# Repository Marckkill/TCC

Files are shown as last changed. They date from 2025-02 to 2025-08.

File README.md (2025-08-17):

# TCC - Sistema de Controle de Motor Trifásico com ESP32

Este repositório contém o projeto de TCC (Trabalho de Conclusão de Curso) que implementa um sistema de controle de motor trifásico utilizando ESP32 com modulação SPWM (Sinusoidal Pulse Width Modulation).

## 📋 Sobre o Projeto

O sistema desenvolvido é um inversor trifásico baseado no microcontrolador ESP32-S3, capaz de gerar sinais SPWM para acionamento de motores AC trifásicos. O projeto inclui monitoramento em tempo real de corrente e tensão, além de sistemas de proteção e segurança.

### Características Principais

- **Controle SPWM**: Modulação senoidal PWM trifásica com frequência configurável
- **Monitoramento em Tempo Real**: Leitura contínua de tensão e corrente RMS
- **Sistema de Proteção**: Detecção de sobrecorrente, sobretensão e falhas do sistema
- **Interface Serial**: Controle e monitoramento via comandos seriais
- **Hardware Personalizado**: PCB desenvolvida especificamente para o projeto

## 📁 Estrutura do Projeto

```
TCC/
├── 📄 Esquemáticos KiCad
│   ├── TCC.kicad_sch           # Esquemático principal
│   ├── filtro.kicad_sch        # Circuito de filtros
│   ├── fonte.kicad_sch         # Sistema de alimentação
│   ├── mcu.kicad_sch           # Microcontrolador ESP32
│   ├── sdf.kicad_sch           # Sistema de detecção de falhas
│   └── smp.kicad_sch           # Sistema de medição de potência
│
├── 🔧 Hardware
│   ├── TCC.kicad_pcb           # Layout da PCB
│   ├── TCC.kicad_pro           # Projeto KiCad
│   └── Componentes_Custom/     # Componentes personalizados
│       ├── ESP32/              # Footprint ESP32-S3
│       ├── FSBB30CH60/         # Módulo de potência
│       └── PJ320A/             # Conector de áudio
│
├── 💻 Firmware
│   └── Firmware.ino            # Código principal do ESP32
│
├── 📚 Documentação
│   ├── TCC.pdf                 # Documentação completa
│   ├── TCC-Fonte.pdf           # Esquemático da fonte
│   ├── TCC-MCU.pdf             # Esquemático do MCU
│   └── TCC-SMP.pdf             # Sistema de medição
│
└── 🔄 Backups
    └── TCC-backups/            # Backups automáticos do projeto
```

## 🔧 Hardware

### Componentes Principais

| Componente | Modelo/Tipo | Função |
| --- | --- | --- |
| **Microcontrolador** | ESP32-S3 | Controle principal do sistema  |
| **Módulo de Potência** | FSBB30CH60C | Inversor trifásico de potência |
| **Sensores de Corrente** | SCT013 (6x) | Monitoramento de corrente AC |
| **Sensores de Tensão** | ZMPT (3x) | Monitoramento de tensão AC |
| **Conector** | PJ320A | Interface de entrada de áudio  |

### Especificações Técnicas

- **Tensão de Entrada**: Barramento DC variável
- **Frequência de Saída**: 50 Hz (configurável)
- **Frequência PWM**: 10 kHz
- **Corrente Máxima**: 5A por fase (com proteção)
- **Tempo Morto**: 2μs entre chaves complementares
- **Taxa de Amostragem ADC**: 20 kHz

### Pinagem do ESP32-S3

#### Sinais PWM

```
Fase U: GPIO 18 (Alto), GPIO 35 (Baixo)
Fase V: GPIO 13 (Alto), GPIO 21 (Baixo)
Fase W: GPIO 14 (Alto), GPIO 17 (Baixo)
```

#### Sensores de Corrente (ADC1)

```
U_IN:  GPIO 1  (ADC1_CH0)    U_OUT: GPIO 2  (ADC1_CH1)
V_IN:  GPIO 3  (ADC1_CH2)    V_OUT: GPIO 4  (ADC1_CH3)
W_IN:  GPIO 5  (ADC1_CH4)    W_OUT: GPIO 6  (ADC1_CH5)
```

#### Sensores de Tensão (ADC1)

```
Tensão U: GPIO 7  (ADC1_CH6)
Tensão V: GPIO 8  (ADC1_CH7)
Tensão W: GPIO 9  (ADC1_CH8)
Vbus:     GPIO 10 (ADC1_CH9)
```

#### Segurança

```
VFO (Status): GPIO 36 (INPUT_PULLUP)
```

## 💻 Firmware

### Funcionalidades Implementadas

#### 🌊 Geração SPWM

- Modulação senoidal PWM trifásica
- Defasagem de 120° entre fases
- Índice de modulação configurável (0.1 - 1.0)
- Atualização a 1 kHz para suavidade do sinal

#### 📊 Monitoramento em Tempo Real

- **ADC Contínuo com DMA**: 20 kHz de amostragem
- **Cálculo RMS**: Janela deslizante de 400 amostras (20ms)
- **Buffer Circular**: Armazenamento eficiente de dados
- **Multitarefa**: Processamento paralelo com FreeRTOS

#### 🛡️ Sistema de Proteção

- **Sobrecorrente**: Trip em >5A por fase
- **Sobretensão**: Monitoramento do barramento DC
- **Status VFO**: Verificação do módulo de potência
- **Parada de Emergência**: Desabilitação imediata em falhas

#### 📡 Interface Serial

Comandos disponíveis:

```
start              - Iniciar o inversor
stop               - Parar o inversor
status             - Mostrar status do sistema
sensors            - Mostrar leituras dos sensores
reset              - Limpar falhas do sistema
set_mod <valor>    - Definir índice de modulação (0.1-1.0)
help               - Mostrar ajuda
```

### Principais Funções do Código

| Função | Descrição |
| --- | --- |
| `setup_mcpwm()` | Configuração do módulo MCPWM para SPWM |
| `setup_adc_continuous()` | Inicialização do ADC contínuo com DMA  |
| `update_spwm()` | Atualização dos duty cycles senoidais  |
| `calculate_rms_from_buffer()` | Cálculo RMS das amostras |
| `check_safety_conditions()` | Verificação das condições de segurança |
| `emergency_stop()` | Parada de emergência do sistema |

## 🚀 Como Usar

### Pré-requisitos

#### Software

- [Arduino IDE](https://www.arduino.cc/en/software) 2.0+
- [KiCad](https://www.kicad.org/) 7.0+ (para visualizar esquemáticos)
- Bibliotecas ESP32 (esp32 by Espressif Systems)

#### Hardware

- ESP32-S3 Development Board
- Módulo FSBB30CH60C
- Sensores SCT013 e ZMPT
- Fonte de alimentação adequada

### Instalação e Configuração

1. **Clone o repositório**:

   ```bash
   git clone https://github.com/usuario/TCC.git
   cd TCC
   ```

2. **Configure o Arduino IDE**:

   - Instale o pacote ESP32
   - Selecione "ESP32S3 Dev Module"
   - Configure a porta serial correta

3. **Compile e envie o firmware**:
   - Abra `Firmware/Firmware.ino`
   - Compile (Ctrl+R)
   - Envie para o ESP32 (Ctrl+U)

### Operação do Sistema

1. **Inicialização**:

   ```
   Sistema inicializado - Pronto para operação
   Comandos: start, stop, status, sensors, reset, set_mod <0.1-1.0>
   AVISO: Verifique todos os sistemas de segurança antes de iniciar!
   ```

2. **Verificar sensores**:

   ```
   sensors
   ```

3. **Iniciar o inversor**:

   ```
   start
   ```

4. **Monitorar operação**:
   ```
   status
   ```

### Exemplo de Uso

```bash
# Monitor serial a 115200 baud
sensors          # Verificar leituras
set_mod 0.5      # Configurar índice de modulação para 50%
start            # Iniciar operação
status           # Verificar status
stop             # Parar operação
```

## 📊 Monitoramento

### Dados Disponíveis

O sistema monitora continuamente:

- **Correntes RMS**: 6 canais (entrada e saída por fase)
- **Tensões RMS**: 3 fases + barramento DC
- **Status de Segurança**: VFO, sobrecorrente, sobretensão
- **Parâmetros SPWM**: Ângulo atual, índice de modulação

### Exemplo de Saída do Monitor

```
=== LEITURAS DOS SENSORES ===
Correntes (A):
  U_IN: 2.34  U_OUT: 2.31
  V_IN: 2.35  V_OUT: 2.33
  W_IN: 2.36  W_OUT: 2.34
Tensões (V):
  U: 230.1  V: 229.8  W: 230.3
Tensão Vbus: 325.4 V
Status VFO: OK
Índice de Modulação: 0.800
=============================
```

## 🛡️ Segurança

### Sistemas de Proteção Implementados

1. **Sobrecorrente**: Monitoramento contínuo com trip em 5A
2. **Sobretensão**: Proteção do barramento DC
3. **VFO**: Monitoramento do status do módulo de potência
4. **Tempo Morto**: Prevenção de curto-circuito entre chaves

### ⚠️ Avisos de Segurança

- **ALTA TENSÃO**: Este projeto trabalha com tensões perigosas
- **Sempre desligue a alimentação** antes de fazer conexões
- **Verifique todas as conexões** antes de energizar
- **Use EPIs adequados** durante testes
- **Tenha um sistema de parada de emergência** sempre acessível

## 🔄 Desenvolvimento

### Estrutura do Código

```cpp
// Configurações principais
#define PWM_FREQUENCY 10000        // 10 kHz
#define MODULATION_FREQUENCY 50    // 50 Hz
#define ADC_SAMPLE_FREQ_HZ 20000   // 20 kHz
#define MAX_CURRENT_AMPS 5.0       // 5A máximo

// Loop principal
void loop() {
    update_spwm();              // Atualiza SPWM (1 kHz)
    update_sensors();           // Lê sensores (100 Hz)
    check_safety_conditions();  // Verifica segurança
    process_serial_commands();  // Processa comandos
}
```

### Tecnologias Utilizadas

- **ESP-IDF**: Framework nativo do ESP32
- **FreeRTOS**: Sistema operacional em tempo real
- **MCPWM**: Módulo PWM dedicado do ESP32
- **ADC Contínuo**: Amostragem de alta velocidade com DMA
- **KiCad**: Design de circuitos e PCB

## 📈 Melhorias Futuras

- [ ] Controle de velocidade com feedback
- [ ] Interface web para controle remoto
- [ ] Controle de torque
- [ ] Algoritmos de controle avançados (FOC)
- [ ] Análise de espectro harmônico
- [ ] Comunicação CAN/Modbus
- [ ] Sistema de logs em cartão SD

## 📄 Documentação

### Arquivos de Documentação

- **[TCC.pdf](TCC.pdf)**: Documentação completa do projeto
- **[TCC-Fonte.pdf](TCC-Fonte.pdf)**: Detalhes do sistema de alimentação
- **[TCC-MCU.pdf](TCC-MCU.pdf)**: Circuito do microcontrolador
- **[TCC-SMP.pdf](TCC-SMP.pdf)**: Sistema de medição de potência

### Referências Técnicas

- [ESP32-S3 Technical Reference Manual](https://www.espressif.com/sites/default/files/documentation/esp32-s3_technical_reference_manual_en.pdf)
- [FSBB30CH60C Datasheet](https://www.onsemi.com/pdf/datasheet/fsbb30ch60c-d.pdf)
- Normas de segurança para inversores de frequência

## 👨‍💻 Autor

**José Fonseca**

- Projeto de TCC - Engenharia Eletrônica

## 📝 Licença

Este projeto foi desenvolvido como Trabalho de Conclusão de Curso (TCC) e está disponível para fins educacionais e de pesquisa.

---

## 🆘 Suporte

Para dúvidas ou problemas:

1. Verifique a documentação técnica incluída
2. Consulte os comentários no código fonte
3. Revise as configurações de hardware
4. Verifique as conexões elétricas

**⚠️ LEMBRE-SE: Segurança sempre em primeiro lugar ao trabalhar com sistemas de potência!**

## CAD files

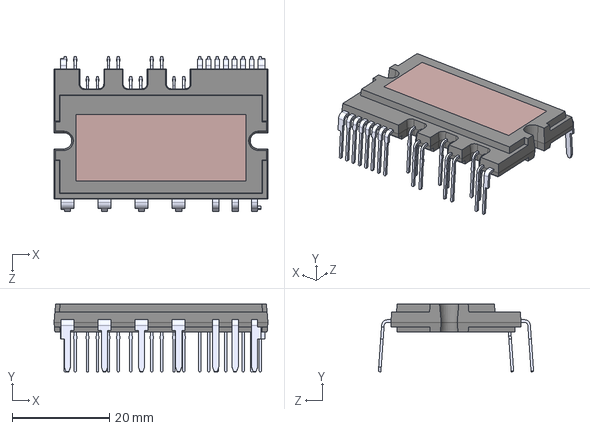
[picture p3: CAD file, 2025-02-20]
Componentes_Custom/FSBB30CH60/FSBB30CH60C.STEP
44.0 x 13.9 x 31.9 mm

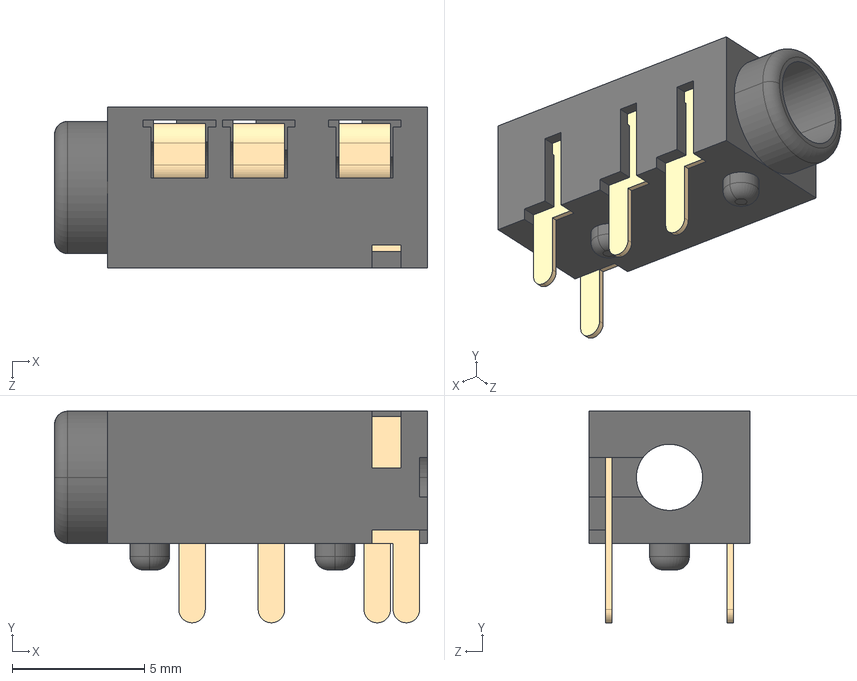
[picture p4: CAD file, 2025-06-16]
Componentes_Custom/PJ320A/PJ320A.STEP
14.1 x 8.00 x 6.10 mm
PJ320A蝶褲
PJ320A-Pin-A x 3
PJ320A-Pin-B

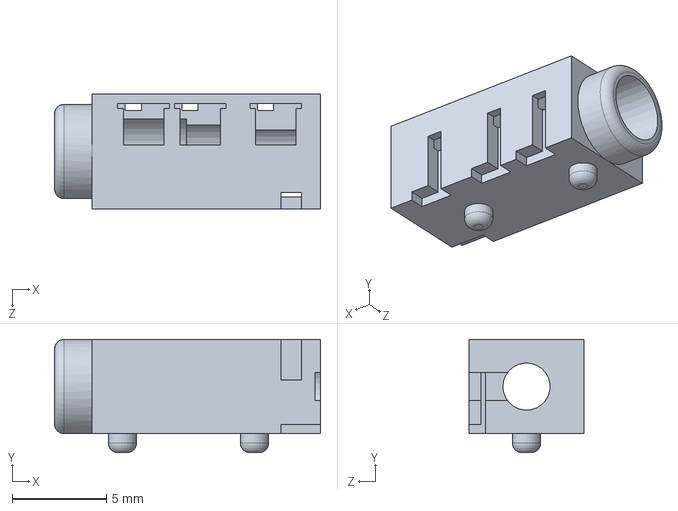
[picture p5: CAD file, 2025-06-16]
Componentes_Custom/PJ320A/PJ320A胶壳.SLDPRT
14.1 x 6.00 x 6.10 mm

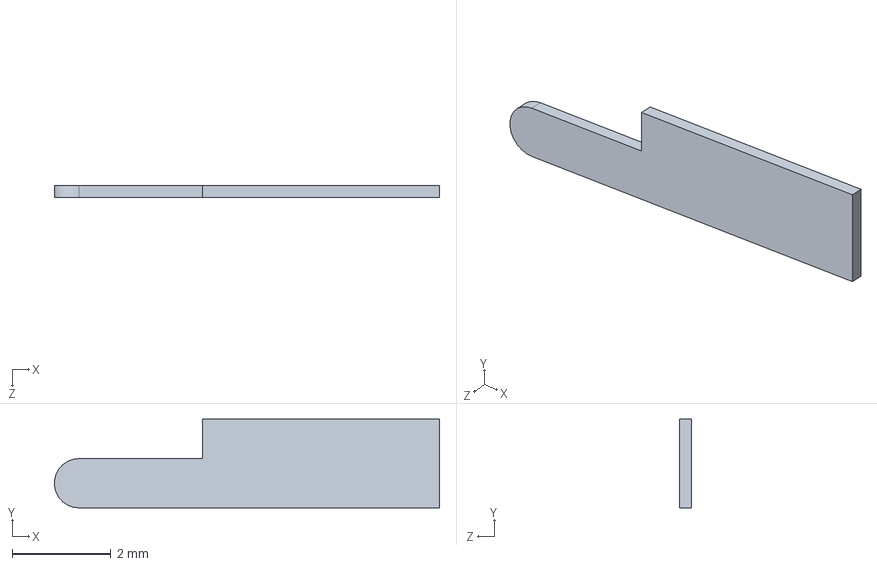
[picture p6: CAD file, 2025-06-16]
Componentes_Custom/PJ320A/PJ320A-Pin-B.sldprt
7.80 x 1.80 x 0.25 mm

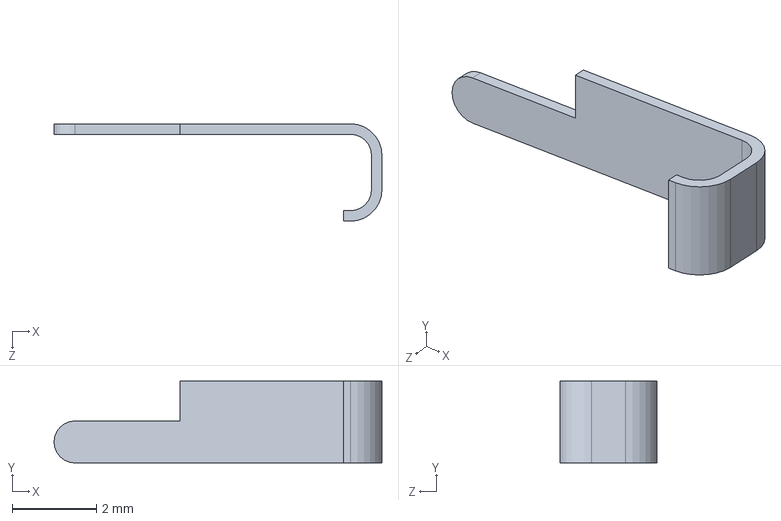
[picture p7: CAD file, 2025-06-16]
Componentes_Custom/PJ320A/PJ320A-Pin-A.sldprt
7.80 x 1.95 x 2.32 mm

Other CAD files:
Componentes_Custom/PJ320A/PJ320A.SLDASM

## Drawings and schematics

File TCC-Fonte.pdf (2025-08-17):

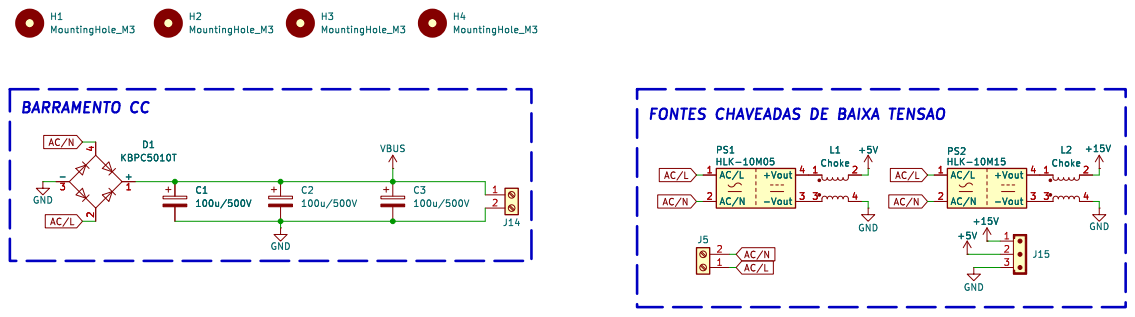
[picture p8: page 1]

Id: 2/4 Title: Fonte de Entrada do Inversor File: fonte.kicad_sch Sheet: /Fonte/ Autor: þÿJosé Fonseca UFPEL GSIC

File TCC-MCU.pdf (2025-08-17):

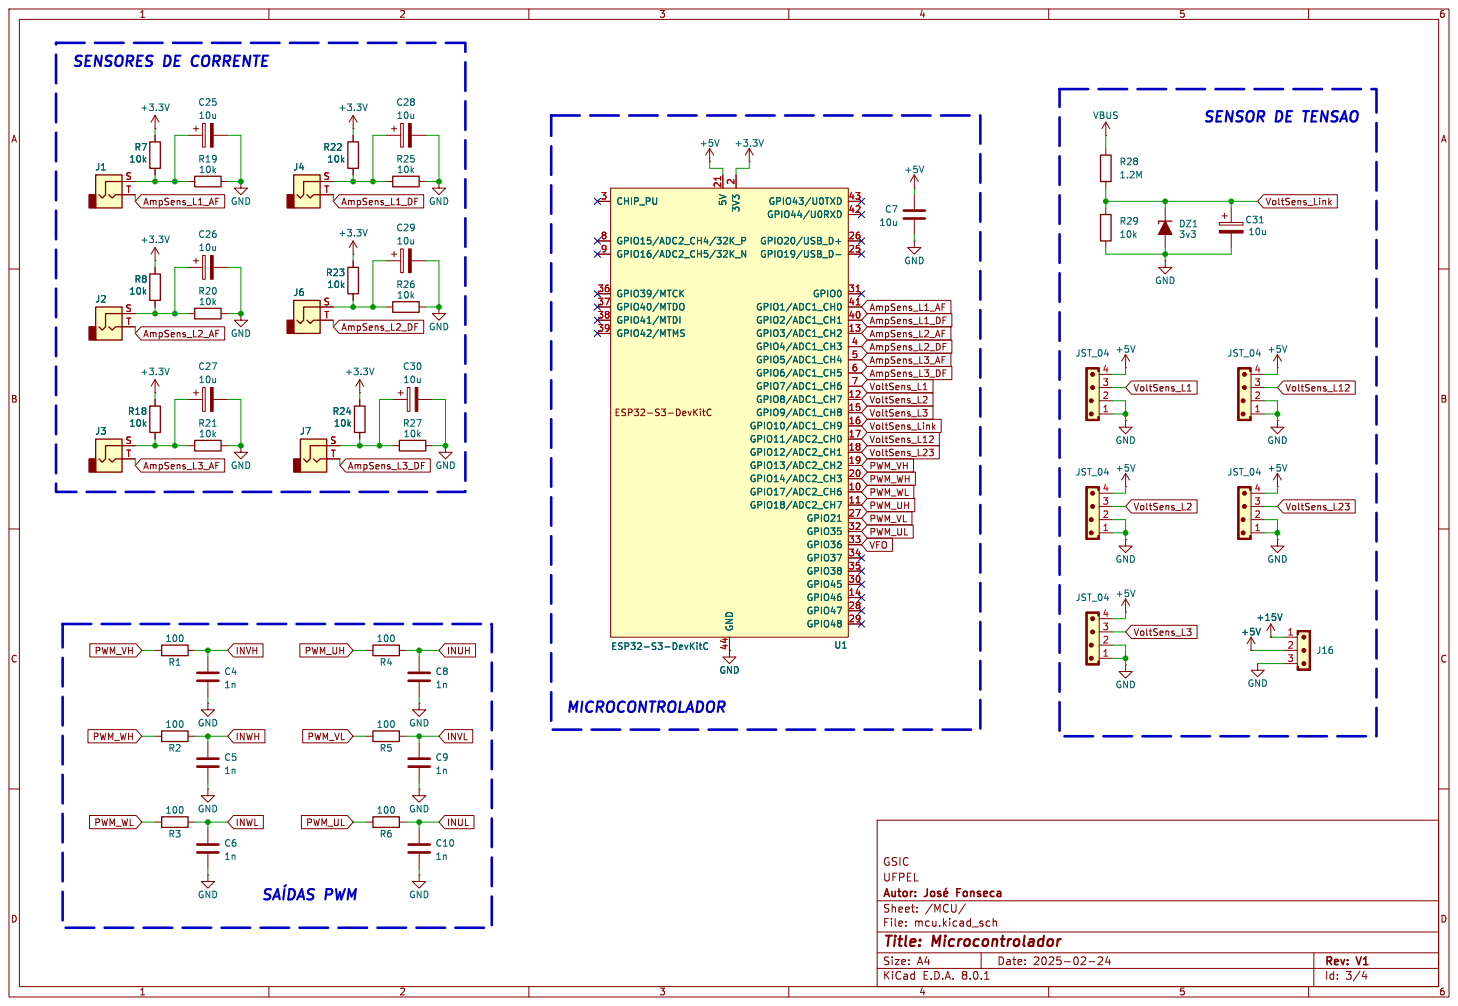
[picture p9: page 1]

2 GPIO17/ADC2_CH6 10 GPIO18/ADC2_CH7 11 GPIO8/ADC1_CH7 12 GPIO3/ADC1_CH2 13 GPIO9/ADC1_CH8 15 GPIO10/ADC1_CH9 16 GPIO11/ADC2_CH0 17 GPIO12/ADC2_CH1 18 GPIO14/ADC2_CH3 20 5V 21 GPIO19/USB_D- 25 GPIO20/USB_D+ 26 GPIO21 27 GPIO47 28 GPIO48 29 CHIP_PU 3 GPIO45 30 GPIO0 31 GPIO35 32 GPIO36 33 GPIO37 34 GPIO38 35 GPIO39/MTCK 36 GPIO40/MTDO 37 GPIO41/MTDI 38 GPIO4/ADC1_CH3 4 GPIO5/ADC1_CH4 5 GPIO6/ADC1_CH5 6 GPIO7/ADC1_CH6 7 GPIO15/ADC2_CH4/32K_P 8 GPIO16/ADC2_CH5/32K_N 9 ESP32-S3-DevKitC U1

2 GPIO17/ADC2_CH6 10 GPIO18/ADC2_CH7 11 GPIO8/ADC1_CH7 12 GPIO3/ADC1_CH2 13 GPIO9/ADC1_CH8 15 GPIO10/ADC1_CH9 16 GPIO11/ADC2_CH0 17 GPIO12/ADC2_CH1 18 GPIO14/ADC2_CH3 20 5V 21 GPIO19/USB_D- 25 GPIO20/USB_D+ 26 GPIO21 27 GPIO47 28 GPIO48 29 CHIP_PU 3 GPIO45 30 GPIO0 31 GPIO35 32 GPIO36 33 GPIO37 34 GPIO38 35 GPIO39/MTCK 36 GPIO40/MTDO 37 GPIO41/MTDI 38 GPIO4/ADC1_CH3 4 GPIO5/ADC1_CH4 5 GPIO6/ADC1_CH5 6 GPIO7/ADC1_CH6 7 GPIO15/ADC2_CH4/32K_P 8 GPIO16/ADC2_CH5/32K_N 9 GND

Id: 3/4 Title: Microcontrolador File: mcu.kicad_sch Sheet: /MCU/ Autor: þÿJosé Fonseca UFPEL GSIC

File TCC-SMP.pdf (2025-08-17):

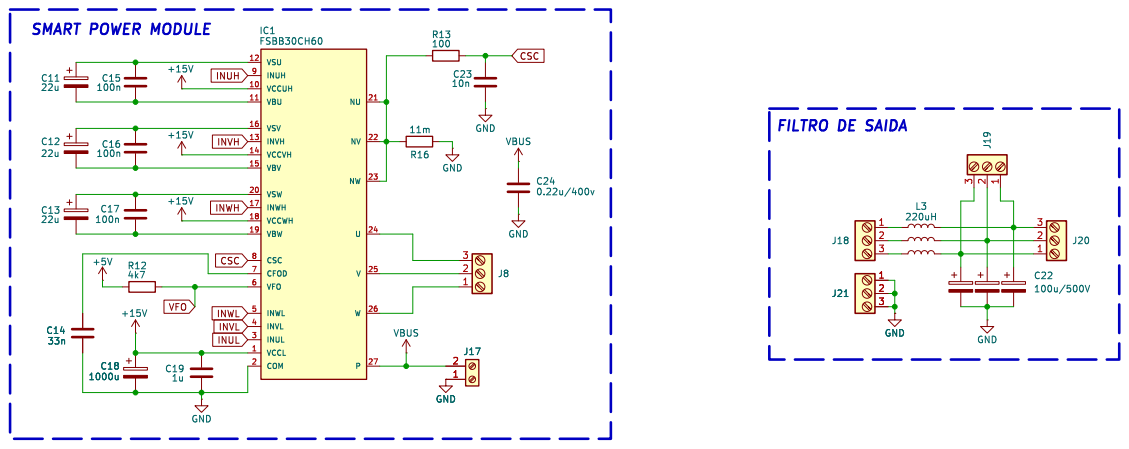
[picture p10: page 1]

INWL SMART POWER MODULE

FILTRO DE SAIDA

File: smp.kicad_sch Sheet: /SMP/ Autor: þÿJosé Fonseca UFPEL GSIC

Id: 4/4 Title: Smart Power Module

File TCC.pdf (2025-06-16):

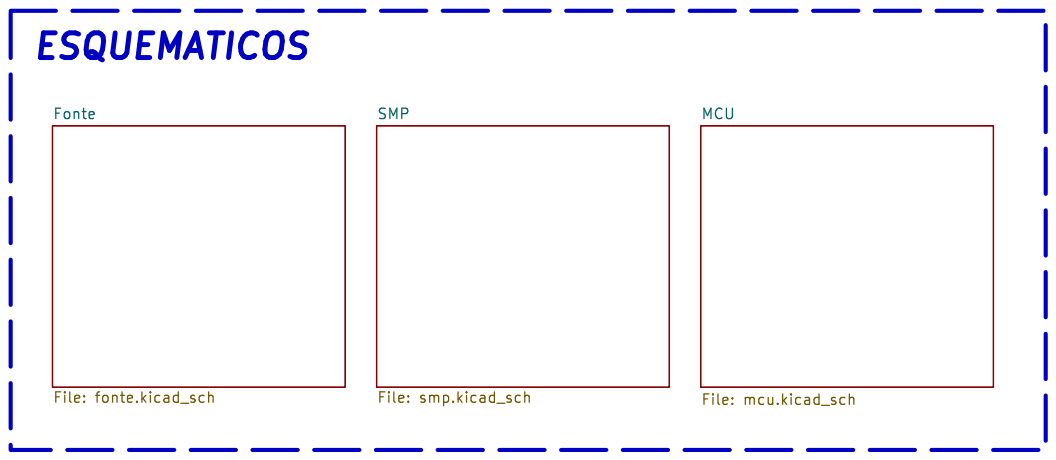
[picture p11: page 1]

File: smp.kicad_sch Fonte File: fonte.kicad_sch ESQUEMATICOS
File: TCC.kicad_sch Sheet: / Autor: þÿJosé Fonseca UFPEL MCU

Id: 1/4 Title: Inversor de Bancada


Id: 2/4 Title: Fonte de Entrada do Inversor File: fonte.kicad_sch Sheet: /Fonte/ Autor: þÿJosé Fonseca UFPEL GSIC

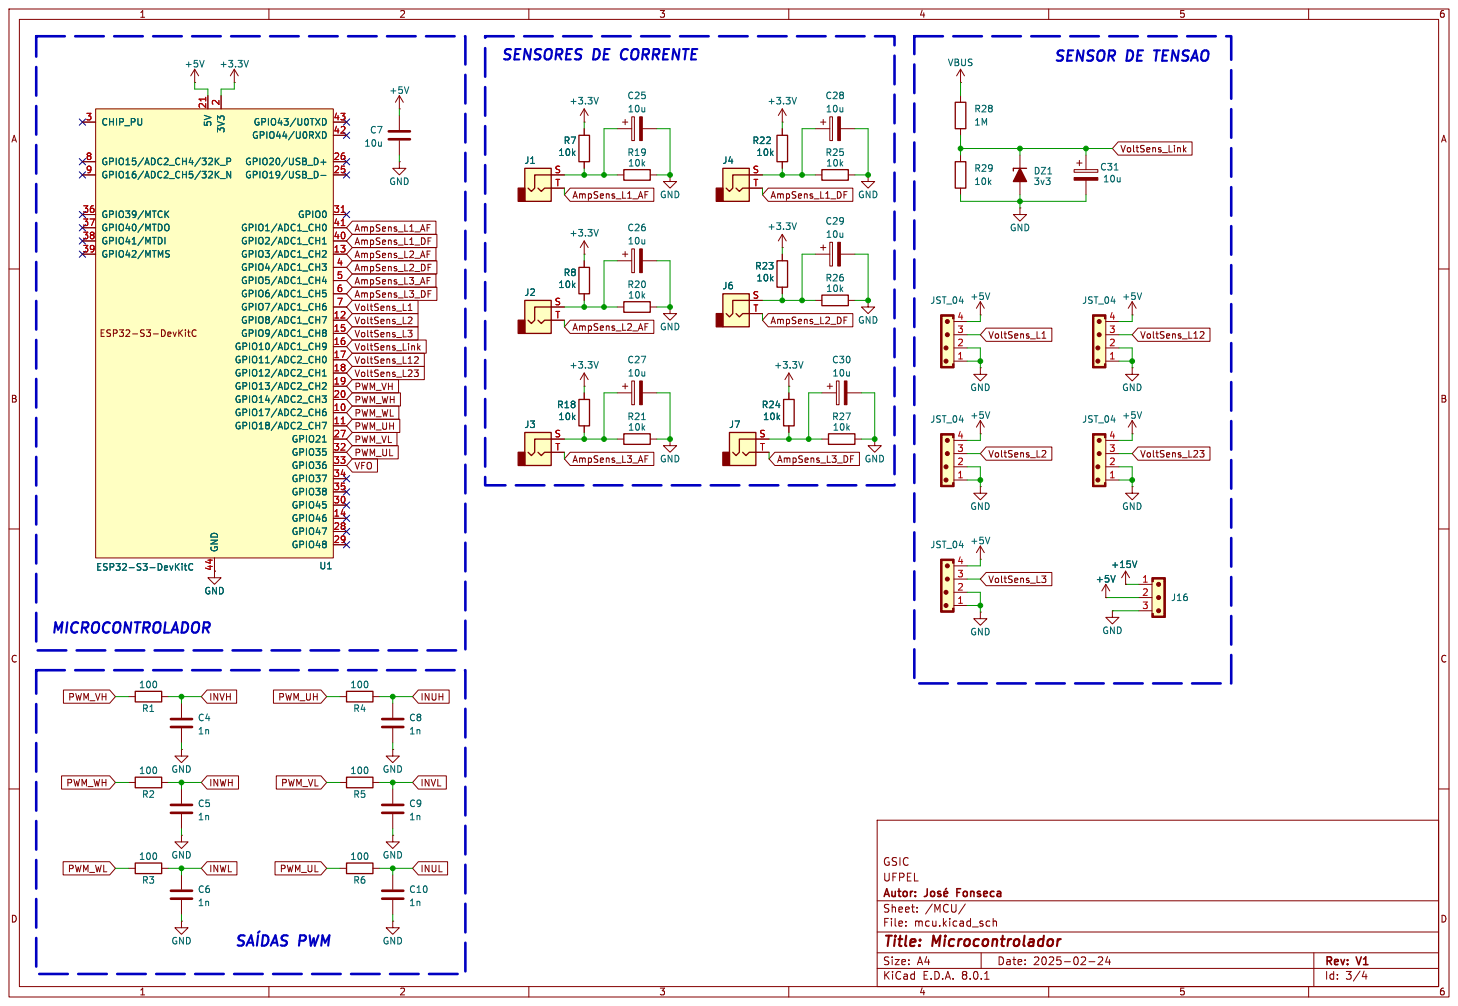
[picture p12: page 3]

2 GPIO17/ADC2_CH6 10 GPIO18/ADC2_CH7 11 GPIO8/ADC1_CH7 12 GPIO3/ADC1_CH2 13 GPIO9/ADC1_CH8 15 GPIO10/ADC1_CH9 16 GPIO11/ADC2_CH0 17 GPIO12/ADC2_CH1 18 GPIO14/ADC2_CH3 20 5V 21 GPIO19/USB_D- 25 GPIO20/USB_D+ 26 GPIO21 27 GPIO47 28 GPIO48 29 CHIP_PU 3 GPIO45 30 GPIO0 31 GPIO35 32 GPIO36 33 GPIO37 34 GPIO38 35 GPIO39/MTCK 36 GPIO40/MTDO 37 GPIO41/MTDI 38 GPIO4/ADC1_CH3 4 GPIO5/ADC1_CH4 5 GPIO6/ADC1_CH5 6 GPIO7/ADC1_CH6 7 GPIO15/ADC2_CH4/32K_P 8 GPIO16/ADC2_CH5/32K_N 9 ESP32-S3-DevKitC U1 C7

2 GPIO17/ADC2_CH6 10 GPIO18/ADC2_CH7 11 GPIO8/ADC1_CH7 12 GPIO3/ADC1_CH2 13 GPIO9/ADC1_CH8 15 GPIO10/ADC1_CH9 16 GPIO11/ADC2_CH0 17 GPIO12/ADC2_CH1 18 GPIO14/ADC2_CH3 20 5V 21 GPIO19/USB_D- 25 GPIO20/USB_D+ 26 GPIO21 27 GPIO47 28 GPIO48 29 CHIP_PU 3 GPIO45 30 GPIO0 31 GPIO35 32 GPIO36 33 GPIO37 34 GPIO38 35 GPIO39/MTCK 36 GPIO40/MTDO 37 GPIO41/MTDI 38 GPIO4/ADC1_CH3 4 GPIO5/ADC1_CH4 5 GPIO6/ADC1_CH5 6 GPIO7/ADC1_CH6 7 GPIO15/ADC2_CH4/32K_P 8 GPIO16/ADC2_CH5/32K_N 9 GND

Id: 3/4 Title: Microcontrolador File: mcu.kicad_sch Sheet: /MCU/ Autor: þÿJosé Fonseca UFPEL GSIC

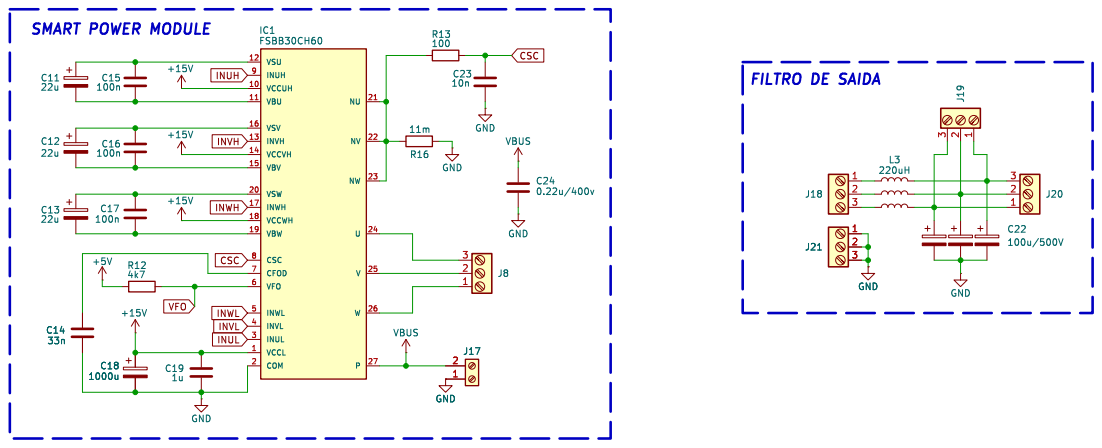
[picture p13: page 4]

File: smp.kicad_sch Sheet: /SMP/ Autor: þÿJosé Fonseca UFPEL GSIC

Id: 4/4 Title: Smart Power Module

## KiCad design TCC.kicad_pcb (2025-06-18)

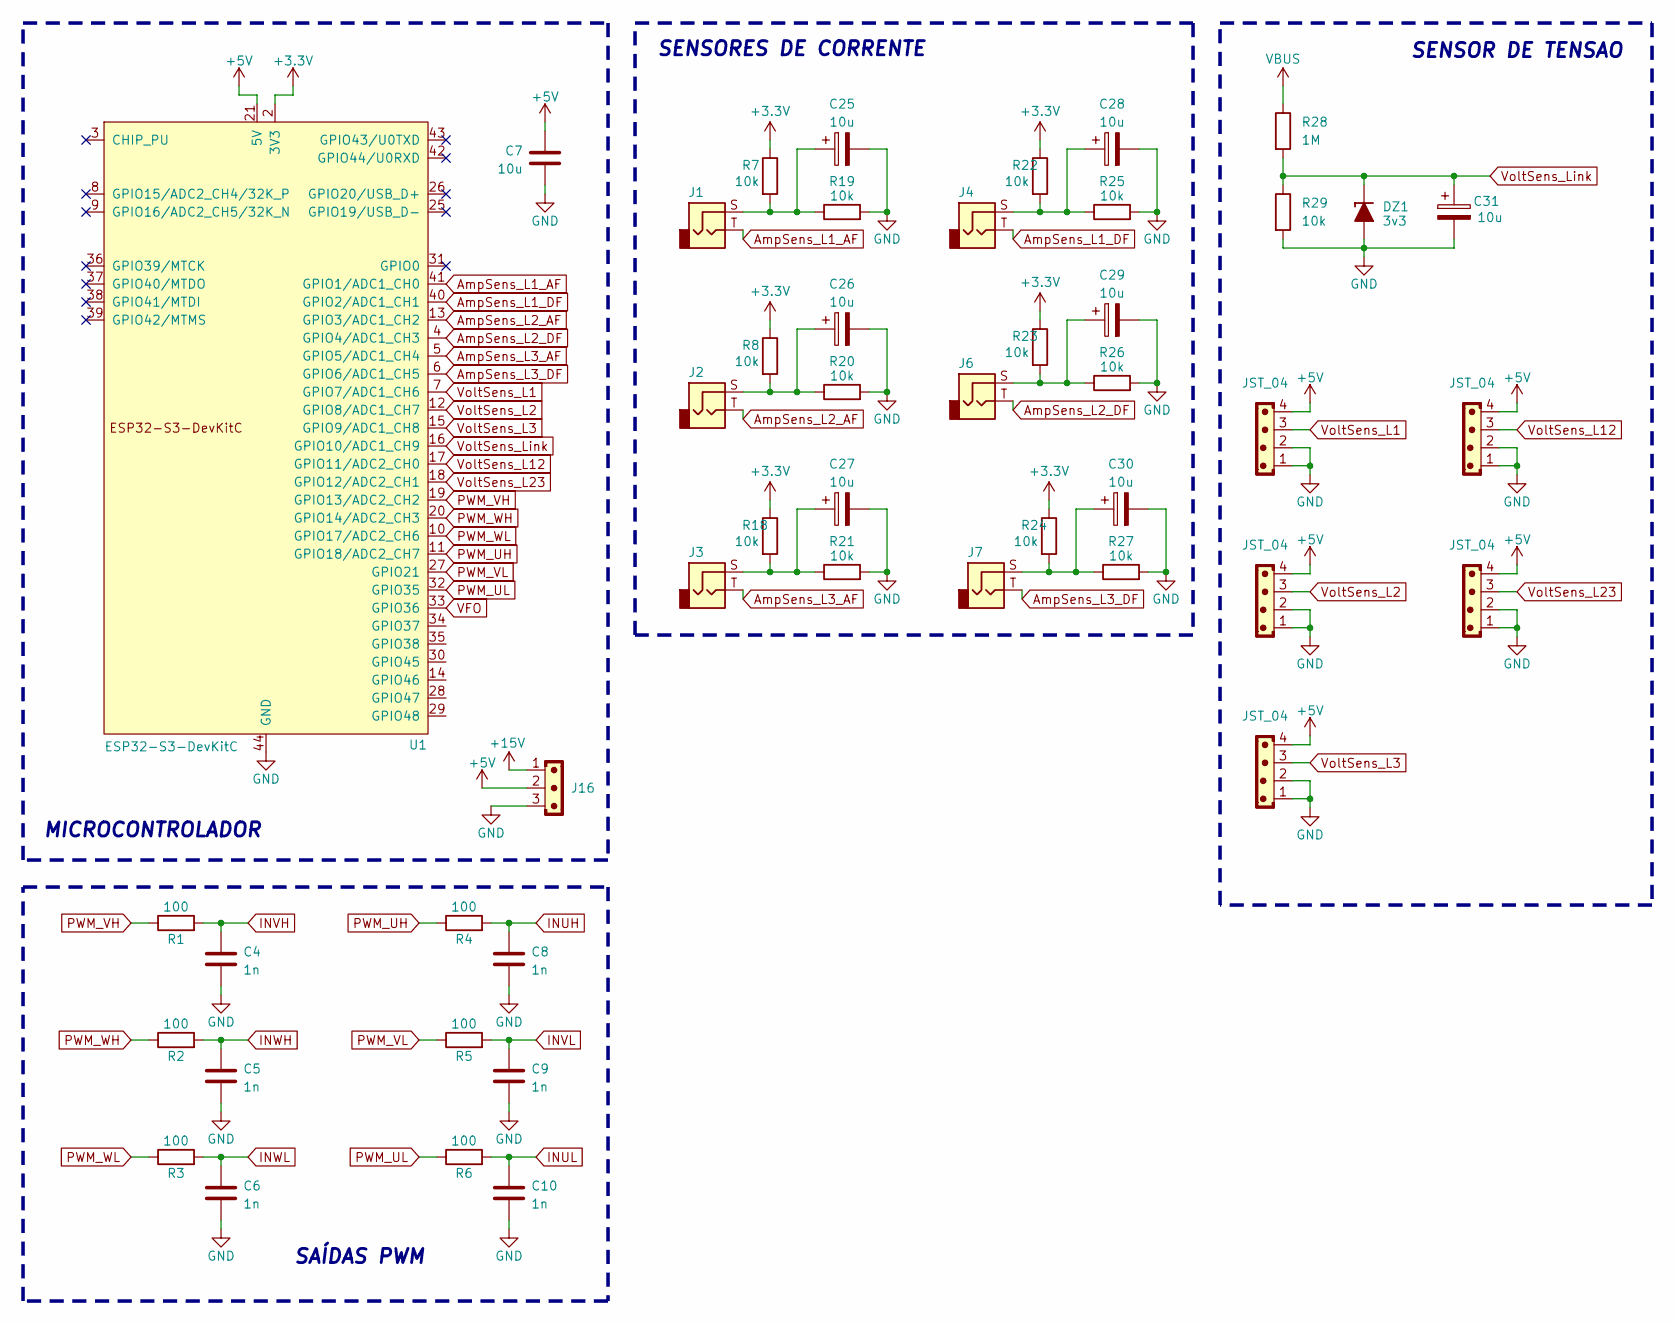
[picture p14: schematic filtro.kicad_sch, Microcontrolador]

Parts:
C4, C5, C6, C8, C9, C10: 1n; C_Disc_D4.7mm_W2.5mm_P5.00mm
C7: 10u; C_Radial_D6.3mm_H5.0mm_P2.50mm
C25, C26, C27, C28, C29, C30, C31: 10u; CP_Radial_D6.3mm_P2.50mm
DZ1: 3v3; D_DO-15_P15.24mm_Horizontal
J1, J2, J3, J4, J6, J7: AudioJack2; Jack_3.5mm_KoreanHropartsElec_PJ-320D-4A_Horizontal
J9, J10, J11, J12, J13: JST_04; JST_EH_B4B-EH-A_1x04_P2.50mm_Vertical
J16: JST_03; JST_EH_B3B-EH-A_1x03_P2.50mm_Vertical
R1, R2, R3, R4, R5, R6: 100; R_Axial_DIN0411_L9.9mm_D3.6mm_P20.32mm_Horizontal
R7, R8, R18, R19, R20, R21, R22, R23, R24, R25, R26, R27, R29: 10k; R_Axial_DIN0411_L9.9mm_D3.6mm_P20.32mm_Horizontal
R28: 1M; R_Axial_DIN0411_L9.9mm_D3.6mm_P20.32mm_Horizontal
U1: ESP32-S3-DevKitC

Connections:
+3.3V: R7.1, R8.1, R18.1, R22.1, R23.1, R24.1, U1.1 (3V3), U1.2 (3V3)
+5V: C7.1, J9.4, J10.4, J11.4, J12.4, J13.4, J16.2, U1.21 (5V); also elsewhere on the board
+15V: J16.1; also elsewhere on the board
AmpSens_L1_AF: J1.T, U1.41 (GPIO1/ADC1_CH0)
AmpSens_L1_DF: J4.T, U1.40 (GPIO2/ADC1_CH1)
AmpSens_L2_AF: J2.T, U1.13 (GPIO3/ADC1_CH2)
AmpSens_L2_DF: J6.T, U1.4 (GPIO4/ADC1_CH3)
AmpSens_L3_AF: J3.T, U1.5 (GPIO5/ADC1_CH4)
AmpSens_L3_DF: J7.T, U1.6 (GPIO6/ADC1_CH5)
GND: C4.2, C5.2, C6.2, C7.2, C8.2, C9.2, C10.2, C25.2, C26.2, C27.2, C28.2, C29.2, C30.2, C31.2, DZ1.2 (A), J9.1, J9.2, J10.1, J10.2, J11.1, J11.2, J12.1, J12.2, J13.1, J13.2, J16.3, R19.2, R20.2, R21.2, R25.2, R26.2, R27.2, R29.2, U1.22 (GND), U1.23 (GND), U1.24 (GND), U1.44 (GND); also elsewhere on the board
INUH: C8.1, R4.2; also elsewhere on the board
INUL: C10.1, R6.2; also elsewhere on the board
INVH: C4.1, R1.2; also elsewhere on the board
INVL: C9.1, R5.2; also elsewhere on the board
INWH: C5.1, R2.2; also elsewhere on the board
INWL: C6.1, R3.2; also elsewhere on the board
unnamed: C25.1, J1.S, R7.2, R19.1
unnamed: C26.1, J2.S, R8.2, R20.1
unnamed: C27.1, J3.S, R18.2, R21.1
unnamed: C28.1, J4.S, R22.2, R25.1
unnamed: C29.1, J6.S, R23.2, R26.1
unnamed: C30.1, J7.S, R24.2, R27.1
PWM_UH: R4.1, U1.11 (GPIO18/ADC2_CH7)
PWM_UL: R6.1, U1.32 (GPIO35)
PWM_VH: R1.1, U1.19 (GPIO13/ADC2_CH2)
PWM_VL: R5.1, U1.27 (GPIO21)
PWM_WH: R2.1, U1.20 (GPIO14/ADC2_CH3)
PWM_WL: R3.1, U1.10 (GPIO17/ADC2_CH6)
VBUS: R28.1; also elsewhere on the board
VFO: U1.33 (GPIO36); also elsewhere on the board
VoltSens_L1: J9.3, U1.7 (GPIO7/ADC1_CH6)
VoltSens_L2: J10.3, U1.12 (GPIO8/ADC1_CH7)
VoltSens_L3: J11.3, U1.15 (GPIO9/ADC1_CH8)
VoltSens_L12: J12.3, U1.17 (GPIO11/ADC2_CH0)
VoltSens_L23: J13.3, U1.18 (GPIO12/ADC2_CH1)
VoltSens_Link: C31.1, DZ1.1 (K), R28.2, R29.1, U1.16 (GPIO10/ADC1_CH9)

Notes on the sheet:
SENSORES DE CORRENTE
MICROCONTROLADOR
SAÍDAS PWM
SENSOR DE TENSAO

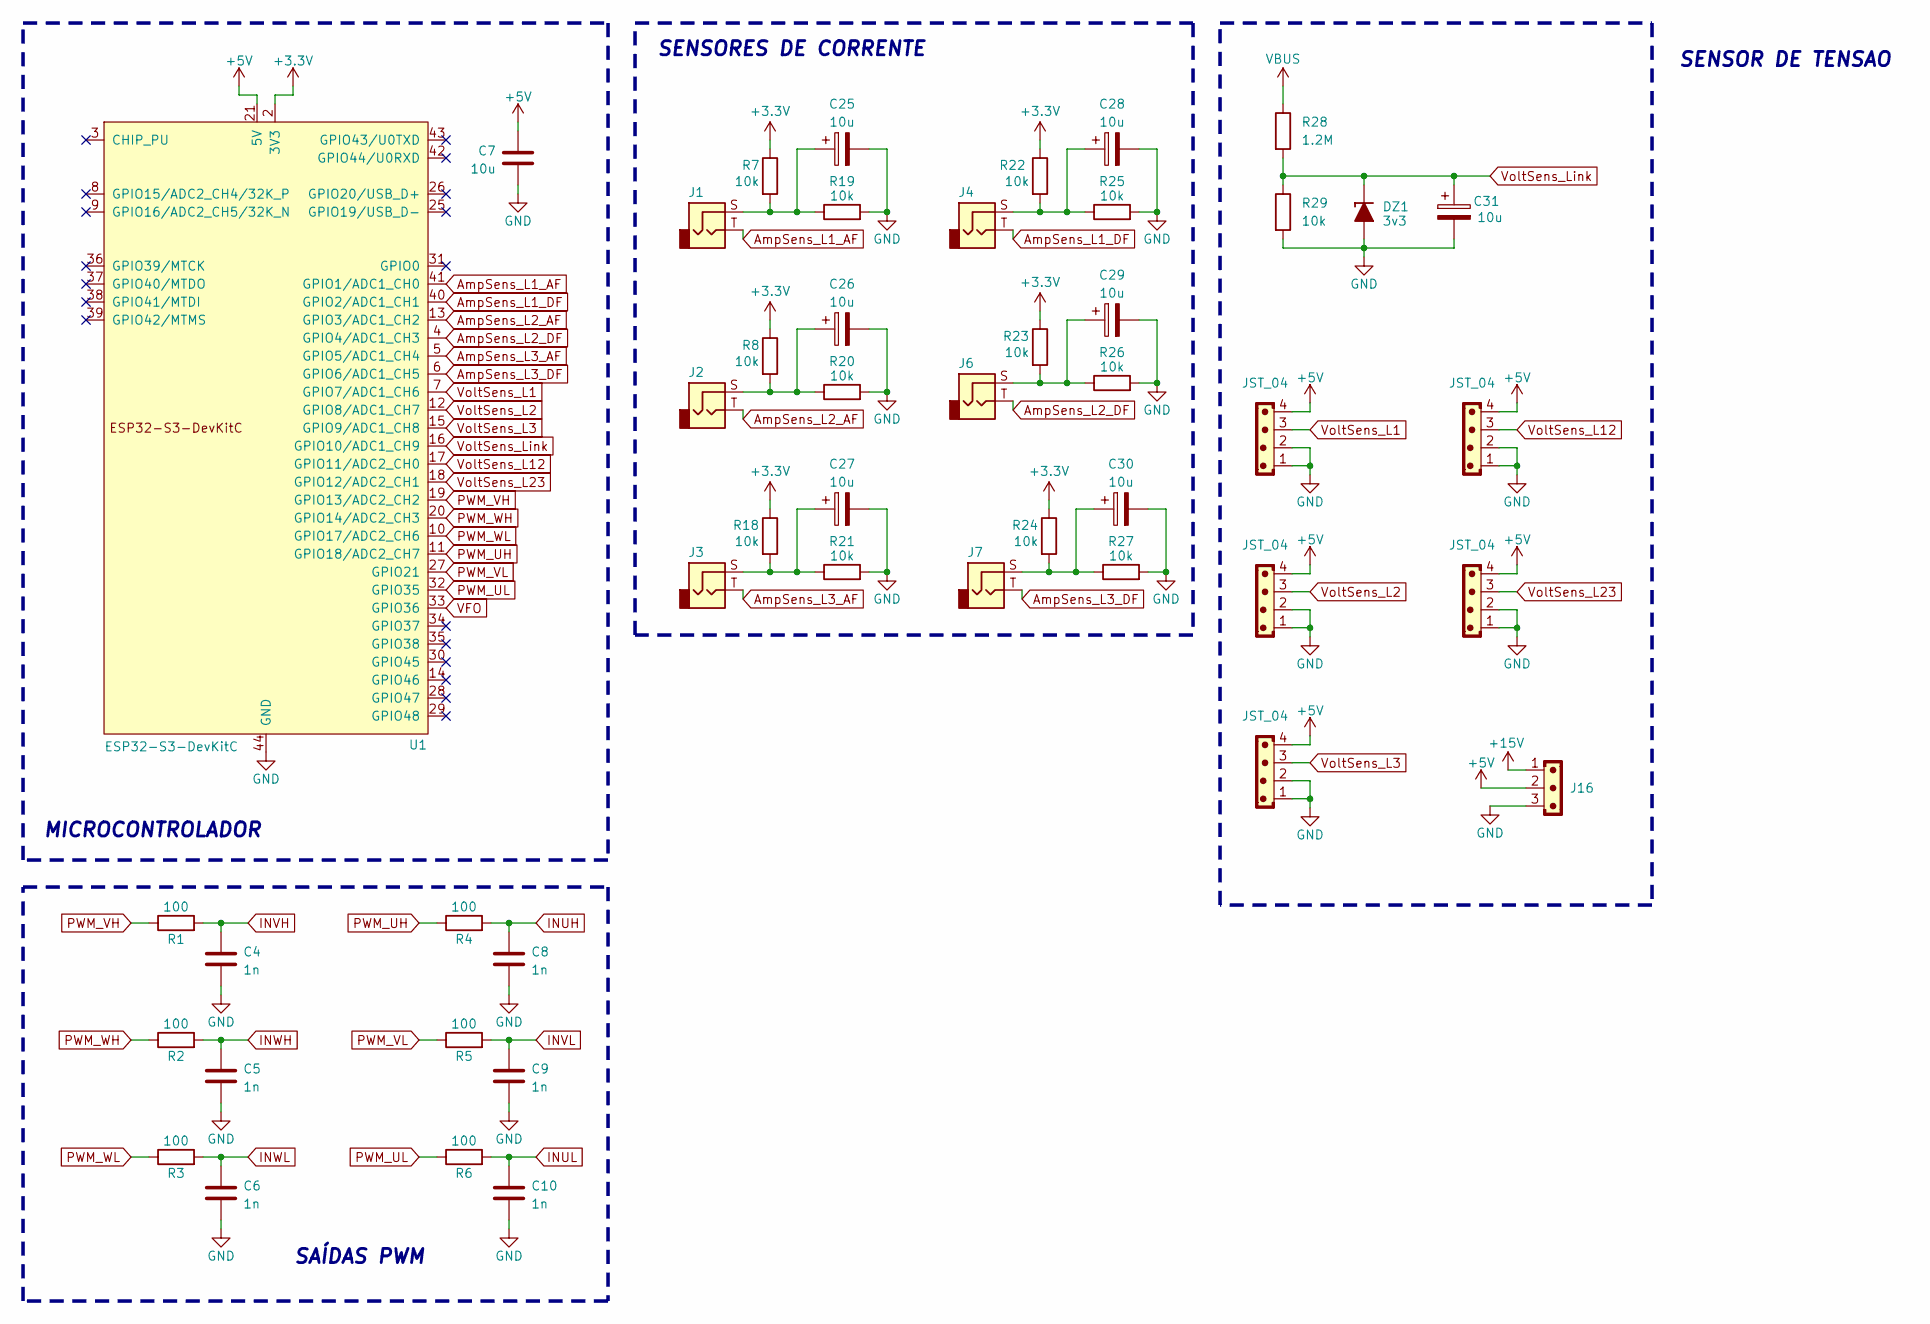
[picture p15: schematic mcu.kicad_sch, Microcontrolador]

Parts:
C4, C5, C6, C8, C9, C10: 1n; C_Disc_D4.7mm_W2.5mm_P5.00mm
C7: 10u; C_Radial_D6.3mm_H5.0mm_P2.50mm
C25, C26, C27, C28, C29, C30, C31: 10u; CP_Radial_D6.3mm_P2.50mm
DZ1: 3v3; D_DO-15_P15.24mm_Horizontal
J1, J2, J3, J4, J6, J7: AudioJack2; Jack_3.5mm_KoreanHropartsElec_PJ-320D-4A_Horizontal
J9, J10, J11, J12, J13: JST_04; JST_EH_B4B-EH-A_1x04_P2.50mm_Vertical
J16: JST_03; JST_EH_B3B-EH-A_1x03_P2.50mm_Vertical
R1, R2, R3, R4, R5, R6: 100; R_Axial_DIN0411_L9.9mm_D3.6mm_P20.32mm_Horizontal
R7, R8, R18, R19, R20, R21, R22, R23, R24, R25, R26, R27, R29: 10k; R_Axial_DIN0411_L9.9mm_D3.6mm_P20.32mm_Horizontal
R28: 1.2M; R_Axial_DIN0411_L9.9mm_D3.6mm_P20.32mm_Horizontal
U1: ESP32-S3-DevKitC

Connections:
+3.3V: R7.1, R8.1, R18.1, R22.1, R23.1, R24.1, U1.1 (3V3), U1.2 (3V3)
+5V: C7.1, J9.4, J10.4, J11.4, J12.4, J13.4, J16.2, U1.21 (5V); also elsewhere on the board
+15V: J16.1; also elsewhere on the board
AmpSens_L1_AF: J1.T, U1.41 (GPIO1/ADC1_CH0)
AmpSens_L1_DF: J4.T, U1.40 (GPIO2/ADC1_CH1)
AmpSens_L2_AF: J2.T, U1.13 (GPIO3/ADC1_CH2)
AmpSens_L2_DF: J6.T, U1.4 (GPIO4/ADC1_CH3)
AmpSens_L3_AF: J3.T, U1.5 (GPIO5/ADC1_CH4)
AmpSens_L3_DF: J7.T, U1.6 (GPIO6/ADC1_CH5)
GND: C4.2, C5.2, C6.2, C7.2, C8.2, C9.2, C10.2, C25.2, C26.2, C27.2, C28.2, C29.2, C30.2, C31.2, DZ1.2 (A), J9.1, J9.2, J10.1, J10.2, J11.1, J11.2, J12.1, J12.2, J13.1, J13.2, J16.3, R19.2, R20.2, R21.2, R25.2, R26.2, R27.2, R29.2, U1.22 (GND), U1.23 (GND), U1.24 (GND), U1.44 (GND); also elsewhere on the board
INUH: C8.1, R4.2; also elsewhere on the board
INUL: C10.1, R6.2; also elsewhere on the board
INVH: C4.1, R1.2; also elsewhere on the board
INVL: C9.1, R5.2; also elsewhere on the board
INWH: C5.1, R2.2; also elsewhere on the board
INWL: C6.1, R3.2; also elsewhere on the board
unnamed: C25.1, J1.S, R7.2, R19.1
unnamed: C26.1, J2.S, R8.2, R20.1
unnamed: C27.1, J3.S, R18.2, R21.1
unnamed: C28.1, J4.S, R22.2, R25.1
unnamed: C29.1, J6.S, R23.2, R26.1
unnamed: C30.1, J7.S, R24.2, R27.1
PWM_UH: R4.1, U1.11 (GPIO18/ADC2_CH7)
PWM_UL: R6.1, U1.32 (GPIO35)
PWM_VH: R1.1, U1.19 (GPIO13/ADC2_CH2)
PWM_VL: R5.1, U1.27 (GPIO21)
PWM_WH: R2.1, U1.20 (GPIO14/ADC2_CH3)
PWM_WL: R3.1, U1.10 (GPIO17/ADC2_CH6)
VBUS: R28.1; also elsewhere on the board
VFO: U1.33 (GPIO36); also elsewhere on the board
VoltSens_L1: J9.3, U1.7 (GPIO7/ADC1_CH6)
VoltSens_L2: J10.3, U1.12 (GPIO8/ADC1_CH7)
VoltSens_L3: J11.3, U1.15 (GPIO9/ADC1_CH8)
VoltSens_L12: J12.3, U1.17 (GPIO11/ADC2_CH0)
VoltSens_L23: J13.3, U1.18 (GPIO12/ADC2_CH1)
VoltSens_Link: C31.1, DZ1.1 (K), R28.2, R29.1, U1.16 (GPIO10/ADC1_CH9)

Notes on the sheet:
SENSORES DE CORRENTE
MICROCONTROLADOR
SAÍDAS PWM
SENSOR DE TENSAO

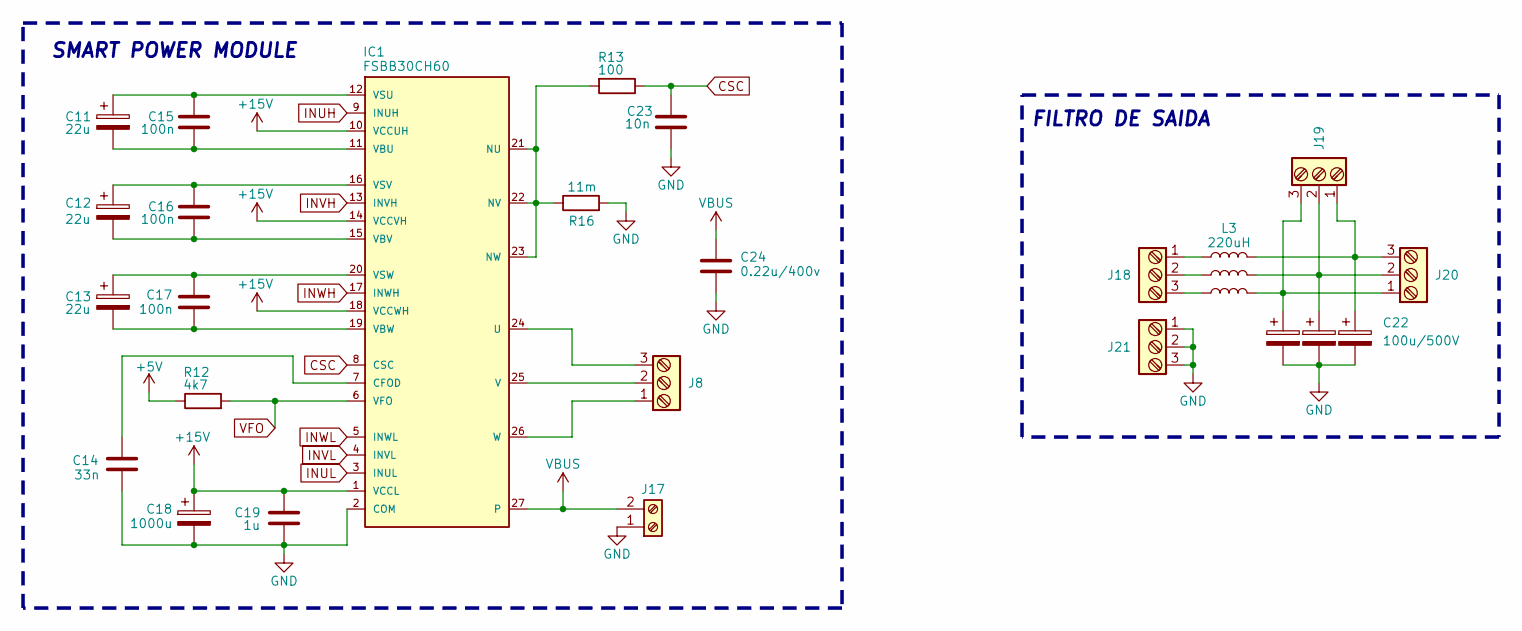
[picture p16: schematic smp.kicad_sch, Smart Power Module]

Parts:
C11, C12, C13: 22u; CP_Radial_D6.3mm_P2.50mm
C14: 33n; C_Disc_D6.0mm_W2.5mm_P5.00mm
C15, C16, C17: 100n; C_Disc_D4.7mm_W2.5mm_P5.00mm
C18: 1000u; CP_Radial_D14.0mm_P5.00mm
C19: 1u; C_Disc_D4.7mm_W2.5mm_P5.00mm
C20, C21, C22: 100u/500V; CP_Radial_D22.0mm_P10.00mm_SnapIn
C23: 10n; C_Disc_D4.7mm_W2.5mm_P5.00mm
C24: 0.22u/400v; C_Rect_L13.5mm_W5.0mm_P10.00mm_FKS3_FKP3_MKS4
IC1: FSBB30CH60; MPN FSBB30CH60B
J8, J18, J19, J20, J21: Screw_Terminal_3_P5.00mm; TerminalBlock_Phoenix_PT-1,5-3-5.0-H_1x03_P5.00mm_Horizontal
J17: Screw_Terminal_01x02; TerminalBlock_Phoenix_MKDS-1,5-2_1x02_P5.00mm_Horizontal
L3, L4, L5: 220uH; L_Toroid_Vertical_L16.0mm_W8.0mm_P7.62mm
R12: 4k7; R_Axial_DIN0411_L9.9mm_D3.6mm_P20.32mm_Horizontal
R13: 100; R_Axial_DIN0411_L9.9mm_D3.6mm_P20.32mm_Horizontal
R16: 11m; R_Bare_Metal_Element_L21.3mm_W4.8mm_P20.30mm

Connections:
+5V: R12.1; also elsewhere on the board
+15V: C18.1, C19.1, IC1.1 (VCCL), IC1.10 (VCCUH), IC1.14 (VCCVH), IC1.18 (VCCWH); also elsewhere on the board
CSC: C23.1, IC1.8 (CSC), R13.1
GND: C14.2, C18.2, C19.2, C20.2, C21.2, C22.2, C23.2, C24.2, IC1.2 (COM), J17.1, J21.1, J21.2, J21.3, R16.2; also elsewhere on the board
INUH: IC1.9 (INUH); also elsewhere on the board
INUL: IC1.3 (INUL); also elsewhere on the board
INVH: IC1.13 (INVH); also elsewhere on the board
INVL: IC1.4 (INVL); also elsewhere on the board
INWH: IC1.17 (INWH); also elsewhere on the board
INWL: IC1.5 (INWL); also elsewhere on the board
unnamed: C20.1, J19.3, J20.1, L5.2
unnamed: C21.1, J19.2, J20.2, L4.2
unnamed: C22.1, J19.1, J20.3, L3.2
unnamed: C14.1, IC1.7 (CFOD)
unnamed: IC1.21 (NU), IC1.22 (NV), IC1.23 (NW), R13.2, R16.1
unnamed: IC1.24 (U), J8.3
unnamed: IC1.25 (V), J8.2
unnamed: C11.2, C15.2, IC1.11 (VBU)
unnamed: C12.2, C16.2, IC1.15 (VBV)
unnamed: C13.2, C17.2, IC1.19 (VBW)
unnamed: C11.1, C15.1, IC1.12 (VSU)
unnamed: C12.1, C16.1, IC1.16 (VSV)
unnamed: C13.1, C17.1, IC1.20 (VSW)
unnamed: IC1.26 (W), J8.1
unnamed: J18.1, L3.1
unnamed: J18.2, L4.1
unnamed: J18.3, L5.1
VBUS: C24.1, IC1.27, J17.2; also elsewhere on the board
VFO: IC1.6 (VFO), R12.2; also elsewhere on the board

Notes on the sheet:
FILTRO DE SAIDA
SMART POWER MODULE

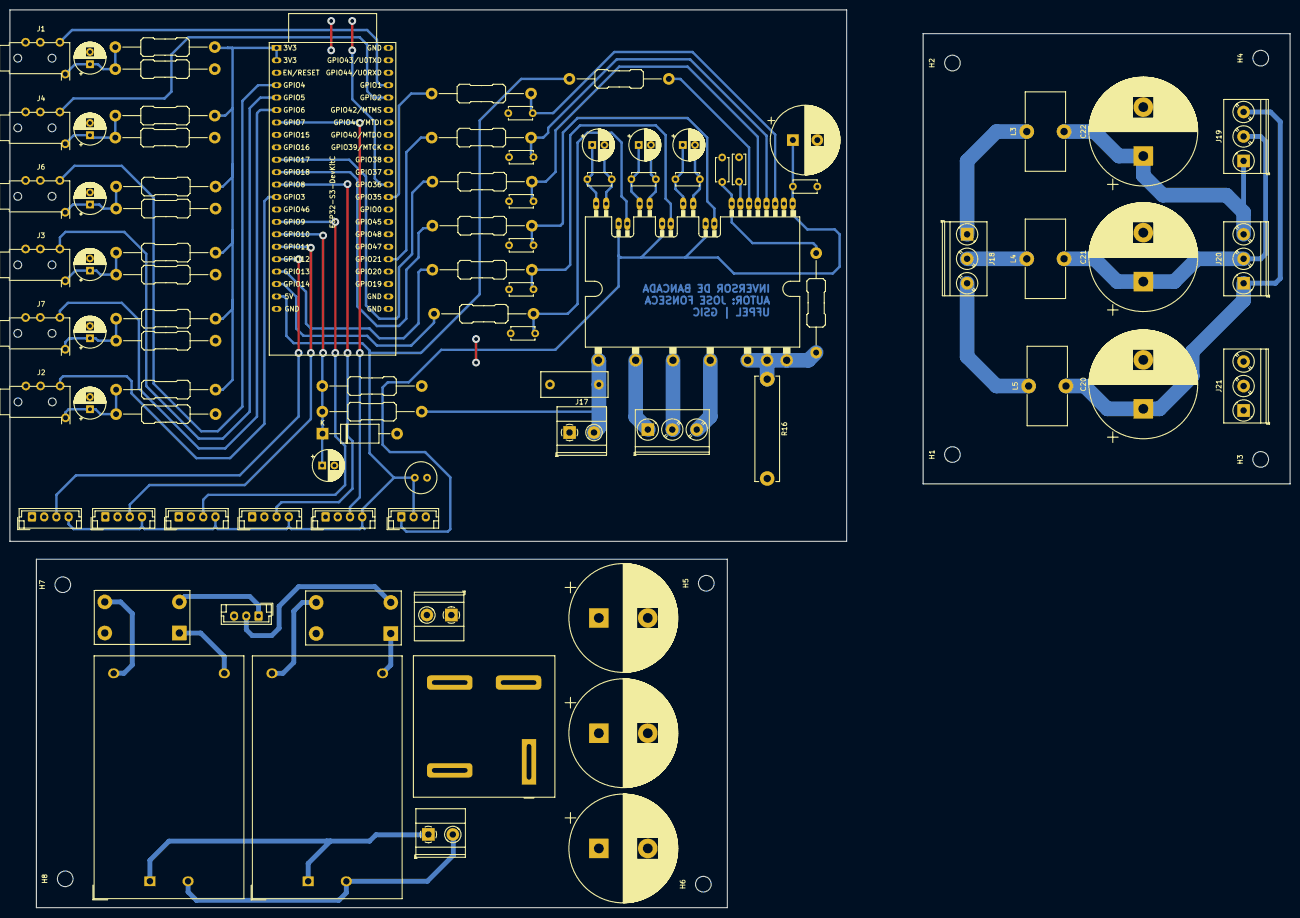
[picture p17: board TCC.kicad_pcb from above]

Board: 2 copper layers, 261.6 x 183.5 mm, 94 parts (0 on the bottom side), 54 nets.

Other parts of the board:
C1, C2, C3: 100u/500V; CP_Radial_D22.0mm_P10.00mm_SnapIn
D1: KBPC5010T; Diode_Bridge_DIGITRON_KBPC_T
H1, H2, H3, H4, H5, H6, H7, H8: MountingHole_M3; MountingHole_3.2mm_M3
J5, J14: Screw_Terminal_01x02; TerminalBlock_Phoenix_MKDS-1,5-2_1x02_P5.00mm_Horizontal
J15: JST_03; JST_EH_B3B-EH-A_1x03_P2.50mm_Vertical
L1, L2: Choke; L_CommonMode_Toroid_Vertical_L19.3mm_W10.8mm_Px6.35mm_Py15.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
PS1: HLK-10M05; Converter_ACDC_Hi-Link_HLK-10Mxx
PS2: HLK-10M15; Converter_ACDC_Hi-Link_HLK-10Mxx

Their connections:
+5V: J15.2, L1.2; also elsewhere on the board
+15V: J15.1, L2.2; also elsewhere on the board
GND: C1.2, C2.2, C3.2, D1.3 (-), J14.2, J15.3, L1.4, L2.4; also elsewhere on the board
VBUS: C1.1, C2.1, C3.1, D1.1 (+), J14.1; also elsewhere on the board

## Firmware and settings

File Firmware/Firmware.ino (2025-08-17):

/*
 * ESP32-S3 MCPWM Inversor trifasico
 * Hardware Alvo: ESP32-S3
 * Módulo Inversor: FSBB30CH60C
 * Framework: Arduino
 * Autor: José Fonseca
 *
 *
 * Características:
 * - Geração de SPWM de 3 fases
 * - Monitoramento de 6 sensores de corrente SCT013
 * - Monitoramento de 3 sensores de tensão ZMPT
 * - Proteção contra sobrecorrente (>5A disparo)
 * - Monitoramento do pino de segurança VFO
 * - Interface serial para usuário
 * - Monitoramento de sensores em tempo real
 *
 * Pinagem:
 * Fase U, Lado Alto:  GPIO 18    |  Sensores de Corrente (ADC1):
 * Fase U, Lado Baixo: GPIO 35    |  - AmpSens_L1_AF: GPIO 1  (ADC1_CH0)
 * Fase V, Lado Alto:  GPIO 13    |  - AmpSens_L1_DF: GPIO 2  (ADC1_CH1)
 * Fase W, Lado Alto:  GPIO 14    |  - AmpSens_L2_AF: GPIO 3  (ADC1_CH2)
 * Fase W, Lado Baixo: GPIO 17    |  - AmpSens_L2_DF: GPIO 4  (ADC1_CH3)
 * Fase V, Lado Baixo: GPIO 21    |  - AmpSens_L3_AF: GPIO 5  (ADC1_CH4)
 *                                |  - AmpSens_L3_DF: GPIO 6  (ADC1_CH5)
 * Sensores de Tensão (ADC1):     |
 * - VoltSens_L1: GPIO 7  (ADC1_CH6)  |  Segurança:
 * - VoltSens_L2: GPIO 8  (ADC1_CH7)  |  - Pino VFO: GPIO 36 (entrada)
 * - VoltSens_L3: GPIO 9  (ADC1_CH8)  |
 *                                    |  Sensor Vbus (ADC1):
 *                                    |  - VoltSens_Link: GPIO 10 (ADC1_CH9)
 *                                    |    Divisor: Ra=1.2MΩ, Rb=10kΩ
 */

#include "driver/mcpwm_prelude.h"
#include "driver/adc.h"
#include "esp_adc/adc_continuous.h"
#include "esp_adc/adc_cali.h"
#include "esp_adc/adc_cali_scheme.h"
#include "freertos/FreeRTOS.h"
#include "freertos/task.h"
#include "freertos/semphr.h"
#include "math.h"

//============================
// Definições de Pinos
//============================

// Pinos PWM
#define PWM_UH_PIN 18 // Fase U, Lado Alto
#define PWM_UL_PIN 35 // Fase U, Lado Baixo
#define PWM_VH_PIN 13 // Fase V, Lado Alto
#define PWM_VL_PIN 21 // Fase V, Lado Baixo
#define PWM_WH_PIN 14 // Fase W, Lado Alto
#define PWM_WL_PIN 17 // Fase W, Lado Baixo

// Pinos dos Sensores de Corrente (SCT013)
#define SCT013_U_IN_PIN ADC_CHANNEL_0  // GPIO 1 - AmpSens_L1_AF
#define SCT013_U_OUT_PIN ADC_CHANNEL_1 // GPIO 2 - AmpSens_L1_DF
#define SCT013_V_IN_PIN ADC_CHANNEL_2  // GPIO 3 - AmpSens_L2_AF
#define SCT013_V_OUT_PIN ADC_CHANNEL_3 // GPIO 4 - AmpSens_L2_DF
#define SCT013_W_IN_PIN ADC_CHANNEL_4  // GPIO 5 - AmpSens_L3_AF
#define SCT013_W_OUT_PIN ADC_CHANNEL_5 // GPIO 6 - AmpSens_L3_DF

// Pinos dos Sensores de Tensão (ZMPT)
#define ZMPT_U_PIN ADC_CHANNEL_6 // GPIO 7 - VoltSens_L1
#define ZMPT_V_PIN ADC_CHANNEL_7 // GPIO 8 - VoltSens_L2
#define ZMPT_W_PIN ADC_CHANNEL_8 // GPIO 9 - VoltSens_L3

// Sensor de Tensão Vbus (ADC1)
#define VBUS_SENSE_PIN ADC_CHANNEL_9 // GPIO 10 - VoltSens_Link

// Pino de Segurança
#define VFO_PIN 36 // Status VFO do módulo inversor

//=========================
// Configurações SPWM
//=========================

#define PWM_FREQUENCY 10000             // Frequência portadora PWM em Hz
#define PWM_TIMER_RESOLUTION_HZ 1000000 // Resolução do timer MCPWM (1MHz -> 1us tick)
#define PWM_PERIOD_TICKS (PWM_TIMER_RESOLUTION_HZ / PWM_FREQUENCY)
#define DEAD_TIME_NS 2000 // Tempo morto em nanossegundos

// Parâmetros SPWM
#define MODULATION_FREQUENCY 50 // Frequência de saída em Hz (50 Hz para AC de 50Hz)
#define SPWM_UPDATE_FREQ 1000   // Frequência de atualização SPWM em Hz
#define SPWM_UPDATE_PERIOD_MS (1000 / SPWM_UPDATE_FREQ)

// Deslocamentos de fase (em radianos)
#define PHASE_U_OFFSET 0.0
#define PHASE_V_OFFSET (2.0 * M_PI / 3.0) // 120°
#define PHASE_W_OFFSET (4.0 * M_PI / 3.0) // 240°

//=========================================
// Configurações de Segurança e Controle
//=========================================

#define MAX_CURRENT_AMPS 5.0 // Corrente máxima permitida por fase
#define SENSOR_UPDATE_MS 10  // Período de atualização da leitura dos sensores

// Configuração do Modo Contínuo ADC
#define ADC_SAMPLE_FREQ_HZ 20000 // Frequência de amostragem de 20 kHz (400x 50Hz)
#define ADC_CONV_MODE ADC_CONV_SINGLE_UNIT_1
#define ADC_OUTPUT_TYPE ADC_DIGI_OUTPUT_FORMAT_TYPE1
#define ADC_GET_CHANNEL(p_data) ((p_data)->type1.channel)
#define ADC_GET_DATA(p_data) ((p_data)->type1.data)

// Tamanhos dos buffers para DMA
#define ADC_READ_LEN 1024   // Tamanho do buffer DMA
#define ADC_BUFFER_COUNT 4  // Número de buffers DMA
#define RMS_WINDOW_SIZE 400 // Amostras para cálculo RMS (20ms em 20kHz)
#define NUM_ADC_CHANNELS 10 // Total de canais ADC (incluindo Vbus)

// Constantes de calibração dos sensores
#define SCT013_SENSITIVITY 0.066 // Sensibilidade SCT013 (V/A) para versão 30A
#define ZMPT_SENSITIVITY 0.0055  // Sensibilidade ZMPT (V/V) típica
#define ADC_VREF 3300            // Tensão de referência ADC em mV

// Constantes do divisor de tensão Vbus
#define VBUS_R1 1200000.0                                    // Ra = 1.2MΩ (resistor superior)
#define VBUS_R2 10000.0                                      // Rb = 10kΩ (resistor inferior)
#define VBUS_DIVIDER_RATIO ((VBUS_R2) / (VBUS_R1 + VBUS_R2)) // Fator do divisor
#define MAX_VBUS_VOLTAGE 400.0                               // Tensão máxima permitida do barramento (V)

//==================
// Handles Globais
//==================

mcpwm_timer_handle_t timer = NULL;
mcpwm_oper_handle_t oper_u = NULL, oper_v = NULL, oper_w = NULL;
mcpwm_cmpr_handle_t comparator_u = NULL, comparator_v = NULL, comparator_w = NULL;
mcpwm_gen_handle_t generator_uh = NULL, generator_ul = NULL;
mcpwm_gen_handle_t generator_vh = NULL, generator_vl = NULL;
mcpwm_gen_handle_t generator_wh = NULL, generator_wl = NULL;

// Handles ADC
adc_continuous_handle_t adc_handle = NULL;
adc_cali_handle_t adc_cali_handle = NULL;

// Variáveis DMA e amostragem
static uint8_t adc_result[ADC_READ_LEN] = {0};
static SemaphoreHandle_t adc_semaphore = NULL;
static TaskHandle_t adc_task_handle = NULL;

// Buffers circulares para cálculo RMS
static float adc_buffers[NUM_ADC_CHANNELS][RMS_WINDOW_SIZE];
static uint16_t buffer_indices[NUM_ADC_CHANNELS] = {0};
static bool buffers_full[NUM_ADC_CHANNELS] = {false};

//====================
// Variáveis Globais
//====================

// Variáveis SPWM
volatile float spwm_angle = 0.0;
volatile unsigned long last_spwm_update = 0;
volatile bool spwm_enabled = false;
volatile float modulation_index = 0.8; // Índice de modulação fixo (sem controle)

// Variáveis dos Sensores
struct SensorData
{
    float current_u_in, current_u_out;
    float current_v_in, current_v_out;
    float current_w_in, current_w_out;
    float voltage_u, voltage_v, voltage_w;
    float vbus_voltage; // Tensão do barramento DC
    bool vfo_status;
} sensors;

// Variáveis de Segurança
volatile bool overcurrent_trip = false;
volatile bool vfo_trip = false;
volatile bool system_fault = false;
unsigned long last_sensor_update = 0;

//=========================
// Protótipos das Funções
//=========================

void setup_mcpwm(void);
void setup_adc_continuous(void);
void setup_safety_pins(void);
void update_spwm(void);
void update_sensors(void);
void check_safety_conditions(void);
void set_duty_cycle(mcpwm_cmpr_handle_t comparator, float duty_percent);
void enable_spwm(void);
void disable_spwm(void);
void emergency_stop(const char *reason);
float read_adc_channel(adc_channel_t channel);
float read_vbus_voltage(void);
float calculate_current_rms(float adc_voltage);
float calculate_voltage_rms(float adc_voltage);
void process_serial_commands(void);
void print_sensor_data(void);
void adc_processing_task(void *pvParameters);
void process_adc_data(uint8_t *data, uint32_t size);
void add_sample_to_buffer(uint8_t channel_idx, float sample);
float calculate_rms_from_buffer(uint8_t channel_idx);
float adc_raw_to_voltage(uint32_t adc_raw);
static bool IRAM_ATTR adc_continuous_callback(adc_continuous_handle_t handle, const adc_continuous_evt_data_t *edata, void *user_data);

//===============
// Função Setup
//===============

void setup()
{
    Serial.begin(115200);

    // Inicializar todos os subsistemas
    setup_safety_pins();
    setup_adc_continuous();
    setup_mcpwm();

    // Criar tarefa de processamento ADC e semáforo
    adc_semaphore = xSemaphoreCreateBinary();
    xTaskCreate(adc_processing_task, "adc_task", 4096, NULL, 5, &adc_task_handle);

    // Iniciar conversão contínua ADC
    ESP_ERROR_CHECK(adc_continuous_start(adc_handle));

    Serial.println("Sistema inicializado - Pronto para operação");
    Serial.println("Comandos: start, stop, status, sensors, reset, set_mod <0.1-1.0>");
    Serial.println("AVISO: Verifique todos os sistemas de segurança antes de iniciar!");
}

//======================================
// Configuração dos Pinos de Segurança
//======================================

void setup_safety_pins(void)
{
    pinMode(VFO_PIN, INPUT_PULLUP);
    Serial.println("Pinos de segurança configurados");
}

//=====================================
// Função de Configuração ADC Contínuo
//=====================================

void setup_adc_continuous(void)
{
    Serial.println("Inicializando Modo Contínuo ADC com DMA...");

    // Configurar modo contínuo ADC
    adc_continuous_handle_cfg_t adc_config = {
        .max_store_buf_size = ADC_READ_LEN * ADC_BUFFER_COUNT,
        .conv_frame_size = ADC_READ_LEN,
    };
    ESP_ERROR_CHECK(adc_continuous_new_handle(&adc_config, &adc_handle));

    // Configurar padrões de conversão
    adc_digi_pattern_config_t adc_pattern[NUM_ADC_CHANNELS] = {};

    // Sensores de corrente (canais 0-5)
    adc_pattern[0] = {.atten = ADC_ATTEN_DB_11, .channel = SCT013_U_IN_PIN, .unit = ADC_UNIT_1, .bit_width = SOC_ADC_DIGI_MAX_BITWIDTH};
    adc_pattern[1] = {.atten = ADC_ATTEN_DB_11, .channel = SCT013_U_OUT_PIN, .unit = ADC_UNIT_1, .bit_width = SOC_ADC_DIGI_MAX_BITWIDTH};
    adc_pattern[2] = {.atten = ADC_ATTEN_DB_11, .channel = SCT013_V_IN_PIN, .unit = ADC_UNIT_1, .bit_width = SOC_ADC_DIGI_MAX_BITWIDTH};
    adc_pattern[3] = {.atten = ADC_ATTEN_DB_11, .channel = SCT013_V_OUT_PIN, .unit = ADC_UNIT_1, .bit_width = SOC_ADC_DIGI_MAX_BITWIDTH};
    adc_pattern[4] = {.atten = ADC_ATTEN_DB_11, .channel = SCT013_W_IN_PIN, .unit = ADC_UNIT_1, .bit_width = SOC_ADC_DIGI_MAX_BITWIDTH};
    adc_pattern[5] = {.atten = ADC_ATTEN_DB_11, .channel = SCT013_W_OUT_PIN, .unit = ADC_UNIT_1, .bit_width = SOC_ADC_DIGI_MAX_BITWIDTH};

    // Sensores de tensão (canais 6-8)
    adc_pattern[6] = {.atten = ADC_ATTEN_DB_11, .channel = ZMPT_U_PIN, .unit = ADC_UNIT_1, .bit_width = SOC_ADC_DIGI_MAX_BITWIDTH};
    adc_pattern[7] = {.atten = ADC_ATTEN_DB_11, .channel = ZMPT_V_PIN, .unit = ADC_UNIT_1, .bit_width = SOC_ADC_DIGI_MAX_BITWIDTH};
    adc_pattern[8] = {.atten = ADC_ATTEN_DB_11, .channel = ZMPT_W_PIN, .unit = ADC_UNIT_1, .bit_width = SOC_ADC_DIGI_MAX_BITWIDTH};

    // Sensor Vbus (canal 9)
    adc_pattern[9] = {.atten = ADC_ATTEN_DB_11, .channel = VBUS_SENSE_PIN, .unit = ADC_UNIT_1, .bit_width = SOC_ADC_DIGI_MAX_BITWIDTH};

    adc_continuous_config_t dig_cfg = {
        .pattern_num = NUM_ADC_CHANNELS,
        .adc_pattern = adc_pattern,
        .sample_freq_hz = ADC_SAMPLE_FREQ_HZ,
        .conv_mode = ADC_CONV_MODE,
        .format = ADC_OUTPUT_TYPE,
    };

    ESP_ERROR_CHECK(adc_continuous_config(adc_handle, &dig_cfg));

    // Registrar callback
    adc_continuous_evt_cbs_t cbs = {
        .on_conv_done = adc_continuous_callback,
    };
    ESP_ERROR_CHECK(adc_continuous_register_event_callbacks(adc_handle, &cbs, NULL));

    // Inicializar calibração
    adc_cali_curve_fitting_config_t cali_config = {
        .unit_id = ADC_UNIT_1,
        .atten = ADC_ATTEN_DB_11,
        .bitwidth = SOC_ADC_DIGI_MAX_BITWIDTH,
    };
    ESP_ERROR_CHECK(adc_cali_create_scheme_curve_fitting(&cali_config, &adc_cali_handle));

    // Inicializar buffers circulares
    for (int i = 0; i < NUM_ADC_CHANNELS; i++)
    {
        buffer_indices[i] = 0;
        buffers_full[i] = false;
        memset(adc_buffers[i], 0, sizeof(adc_buffers[i]));
    }

    Serial.printf("Modo Contínuo ADC inicializado:\n");
    Serial.printf("- Taxa de Amostragem: %d Hz\n", ADC_SAMPLE_FREQ_HZ);
    Serial.printf("- Canais: %d\n", NUM_ADC_CHANNELS);
    Serial.printf("- Janela RMS: %d amostras (%.1f ms)\n", RMS_WINDOW_SIZE, (float)RMS_WINDOW_SIZE * 1000.0 / ADC_SAMPLE_FREQ_HZ);
}

//========================
// Callback ADC Contínuo
//========================

static bool IRAM_ATTR adc_continuous_callback(adc_continuous_handle_t handle, const adc_continuous_evt_data_t *edata, void *user_data)
{
    BaseType_t mustYield = pdFALSE;
    // Sinalizar tarefa de processamento
    vTaskNotifyGiveFromISR(adc_task_handle, &mustYield);
    return (mustYield == pdTRUE);
}

//===============================
// Tarefa de Processamento ADC
//================================

void adc_processing_task(void *pvParameters)
{
    uint32_t ret_num = 0;

    while (1)
    {
        // Aguardar notificação do callback
        ulTaskNotifyTake(pdTRUE, portMAX_DELAY);

        // Ler dados disponíveis
        esp_err_t ret = adc_continuous_read(adc_handle, adc_result, ADC_READ_LEN, &ret_num, 0);
        if (ret == ESP_OK)
        {
            process_adc_data(adc_result, ret_num);
        }
    }
}

//=======================
// Processar Dados ADC
//=======================

void process_adc_data(uint8_t *data, uint32_t size)
{
    adc_digi_output_data_t *p = NULL;

    for (int i = 0; i < size; i += SOC_ADC_DIGI_RESULT_BYTES)
    {
        p = (adc_digi_output_data_t *)&data[i];

        if (ADC_GET_CHANNEL(p) < NUM_ADC_CHANNELS)
        {
            uint32_t adc_raw = ADC_GET_DATA(p);
            float voltage = adc_raw_to_voltage(adc_raw);
            add_sample_to_buffer(ADC_GET_CHANNEL(p), voltage);
        }
    }
}

//=======================================
// Adicionar Amostra ao Buffer Circular
//=======================================

void add_sample_to_buffer(uint8_t channel_idx, float sample)
{
    if (channel_idx >= NUM_ADC_CHANNELS)
        return;

    adc_buffers[channel_idx][buffer_indices[channel_idx]] = sample;
    buffer_indices[channel_idx]++;

    if (buffer_indices[channel_idx] >= RMS_WINDOW_SIZE)
    {
        buffer_indices[channel_idx] = 0;
        buffers_full[channel_idx] = true;
    }
}

//=========================
// Calcular RMS do Buffer
//=========================

float calculate_rms_from_buffer(uint8_t channel_idx)
{
    if (channel_idx >= NUM_ADC_CHANNELS)
        return 0.0;

    // Aguardar buffer ser preenchido pelo menos uma vez
    if (!buffers_full[channel_idx])
        return 0.0;

    float sum_squares = 0.0;
    uint16_t samples_to_use = RMS_WINDOW_SIZE;

    for (int i = 0; i < samples_to_use; i++)
    {
        float sample = adc_buffers[channel_idx][i];
        sum_squares += sample * sample;
    }

    return sqrt(sum_squares / samples_to_use);
}

//=================================
// Conversão ADC Raw para Tensão
//=================================

float adc_raw_to_voltage(uint32_t adc_raw)
{
    int voltage_mv = 0;
    esp_err_t ret = adc_cali_raw_to_voltage(adc_cali_handle, adc_raw, &voltage_mv);
    if (ret != ESP_OK)
    {
        return 0.0;
    }
    return (float)voltage_mv / 1000.0; // Converter mV para V
}

//================================
// Função de Configuração MCPWM
//================================

void setup_mcpwm(void)
{
    Serial.println("Inicializando MCPWM para SPWM...");

    // Criar timer
    mcpwm_timer_config_t timer_config = {};
    timer_config.group_id = 0;
    timer_config.clk_src = MCPWM_TIMER_CLK_SRC_DEFAULT;
    timer_config.resolution_hz = PWM_TIMER_RESOLUTION_HZ;
    timer_config.count_mode = MCPWM_TIMER_COUNT_MODE_UP;
    timer_config.period_ticks = PWM_PERIOD_TICKS;
    ESP_ERROR_CHECK(mcpwm_new_timer(&timer_config, &timer));

    // Criar operadores
    mcpwm_operator_config_t operator_config = {};
    operator_config.group_id = 0;
    ESP_ERROR_CHECK(mcpwm_new_operator(&operator_config, &oper_u));
    ESP_ERROR_CHECK(mcpwm_new_operator(&operator_config, &oper_v));
    ESP_ERROR_CHECK(mcpwm_new_operator(&operator_config, &oper_w));

    // Conectar operadores ao timer
    ESP_ERROR_CHECK(mcpwm_operator_connect_timer(oper_u, timer));
    ESP_ERROR_CHECK(mcpwm_operator_connect_timer(oper_v, timer));
    ESP_ERROR_CHECK(mcpwm_operator_connect_timer(oper_w, timer));

    // Criar comparadores
    mcpwm_comparator_config_t comparator_config = {};
    comparator_config.flags.update_cmp_on_tez = true;
    ESP_ERROR_CHECK(mcpwm_new_comparator(oper_u, &comparator_config, &comparator_u));
    ESP_ERROR_CHECK(mcpwm_new_comparator(oper_v, &comparator_config, &comparator_v));
    ESP_ERROR_CHECK(mcpwm_new_comparator(oper_w, &comparator_config, &comparator_w));

    // Definir duty cycle inicial
    uint32_t initial_duty_ticks = PWM_PERIOD_TICKS / 2;
    if (initial_duty_ticks >= PWM_PERIOD_TICKS)
    {
        initial_duty_ticks = PWM_PERIOD_TICKS - 1;
    }

    ESP_ERROR_CHECK(mcpwm_comparator_set_compare_value(comparator_u, initial_duty_ticks));
    ESP_ERROR_CHECK(mcpwm_comparator_set_compare_value(comparator_v, initial_duty_ticks));
    ESP_ERROR_CHECK(mcpwm_comparator_set_compare_value(comparator_w, initial_duty_ticks));

    // Criar geradores
    mcpwm_generator_config_t gen_config = {};

    // Geradores Fase U
    gen_config.gen_gpio_num = PWM_UH_PIN;
    ESP_ERROR_CHECK(mcpwm_new_generator(oper_u, &gen_config, &generator_uh));
    gen_config.gen_gpio_num = PWM_UL_PIN;
    ESP_ERROR_CHECK(mcpwm_new_generator(oper_u, &gen_config, &generator_ul));

    // Geradores Fase V
    gen_config.gen_gpio_num = PWM_VH_PIN;
    ESP_ERROR_CHECK(mcpwm_new_generator(oper_v, &gen_config, &generator_vh));
    gen_config.gen_gpio_num = PWM_VL_PIN;
    ESP_ERROR_CHECK(mcpwm_new_generator(oper_v, &gen_config, &generator_vl));

    // Geradores Fase W
    gen_config.gen_gpio_num = PWM_WH_PIN;
    ESP_ERROR_CHECK(mcpwm_new_generator(oper_w, &gen_config, &generator_wh));
    gen_config.gen_gpio_num = PWM_WL_PIN;
    ESP_ERROR_CHECK(mcpwm_new_generator(oper_w, &gen_config, &generator_wl));

    // Configurar ações dos geradores
    ESP_ERROR_CHECK(mcpwm_generator_set_action_on_timer_event(generator_uh,
                                                              MCPWM_GEN_TIMER_EVENT_ACTION(MCPWM_TIMER_DIRECTION_UP, MCPWM_TIMER_EVENT_EMPTY, MCPWM_GEN_ACTION_HIGH)));
    ESP_ERROR_CHECK(mcpwm_generator_set_action_on_compare_event(generator_uh,
                                                                MCPWM_GEN_COMPARE_EVENT_ACTION(MCPWM_TIMER_DIRECTION_UP, comparator_u, MCPWM_GEN_ACTION_LOW)));

    ESP_ERROR_CHECK(mcpwm_generator_set_action_on_timer_event(generator_vh,
                                                              MCPWM_GEN_TIMER_EVENT_ACTION(MCPWM_TIMER_DIRECTION_UP, MCPWM_TIMER_EVENT_EMPTY, MCPWM_GEN_ACTION_HIGH)));
    ESP_ERROR_CHECK(mcpwm_generator_set_action_on_compare_event(generator_vh,
                                                                MCPWM_GEN_COMPARE_EVENT_ACTION(MCPWM_TIMER_DIRECTION_UP, comparator_v, MCPWM_GEN_ACTION_LOW)));

    ESP_ERROR_CHECK(mcpwm_generator_set_action_on_timer_event(generator_wh,
                                                              MCPWM_GEN_TIMER_EVENT_ACTION(MCPWM_TIMER_DIRECTION_UP, MCPWM_TIMER_EVENT_EMPTY, MCPWM_GEN_ACTION_HIGH)));
    ESP_ERROR_CHECK(mcpwm_generator_set_action_on_compare_event(generator_wh,
                                                                MCPWM_GEN_COMPARE_EVENT_ACTION(MCPWM_TIMER_DIRECTION_UP, comparator_w, MCPWM_GEN_ACTION_LOW)));

    // Configurar tempo morto
    const uint32_t dead_time_ticks = (uint32_t)(DEAD_TIME_NS * PWM_TIMER_RESOLUTION_HZ / 1000000000);

    auto configure_dead_time = [dead_time_ticks](mcpwm_gen_handle_t gena, mcpwm_gen_handle_t genb)
    {
        mcpwm_dead_time_config_t dead_time_config = {
            .posedge_delay_ticks = dead_time_ticks,
            .negedge_delay_ticks = 0};
        ESP_ERROR_CHECK(mcpwm_generator_set_dead_time(gena, gena, &dead_time_config));

        dead_time_config.posedge_delay_ticks = 0;
        dead_time_config.negedge_delay_ticks = dead_time_ticks;
        dead_time_config.flags.invert_output = true;
        ESP_ERROR_CHECK(mcpwm_generator_set_dead_time(gena, genb, &dead_time_config));
    };

    configure_dead_time(generator_uh, generator_ul);
    configure_dead_time(generator_vh, generator_vl);
    configure_dead_time(generator_wh, generator_wl);

    // Habilitar e iniciar timer
    ESP_ERROR_CHECK(mcpwm_timer_enable(timer));
    ESP_ERROR_CHECK(mcpwm_timer_start_stop(timer, MCPWM_TIMER_START_NO_STOP));

    Serial.println("Inicialização MCPWM completa!");
}

//=================================================================
// Função de Leitura ADC (Agora usa RMS da amostragem contínua)
//=================================================================
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
void loop()
{
    unsigned long current_time = millis();

    // Atualizar SPWM se habilitado
    if (current_time - last_spwm_update >= SPWM_UPDATE_PERIOD_MS)
    {
        update_spwm();
        last_spwm_update = current_time;
    }

    // Atualizar sensores e verificar segurança
    if (current_time - last_sensor_update >= SENSOR_UPDATE_MS)
    {
        update_sensors();
        check_safety_conditions();
        last_sensor_update = current_time;
    }

    // Processar comandos seriais
    process_serial_commands();

    // Pequeno delay para não sobrecarregar o processador
    delay(1);
}

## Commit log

2025-05-05 change conector
    [TCC.kicad_pcb, mcu.kicad_sch]
2026-11-08 Firmware v2 e relatório de passagem da bancada
    Firmware v2: SPWM calculado na interrupção do PWM de 10 kHz, brake do
    MCPWM para desligar (o VFO corta por hardware), pré-carga do bootstrap,
    rampa e V/f, ADC contínuo no formato TYPE2 com RMS sem o nível CC, e
    serial sem bloqueio. Compilado no core ESP32 3.3.12; não rodou na placa.
    RELATORIO.html: os problemas do esquemático e da montagem em ordem de
    gravidade, por que o v1 não funcionava, como o v2 funciona e o roteiro
    do primeiro teste.
